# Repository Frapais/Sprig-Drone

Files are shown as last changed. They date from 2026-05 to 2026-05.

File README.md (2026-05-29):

# Sprig-Drone — a single-board Flix drone for the Sprig-C3

A compact, single-board build of the open source [**Flix**](https://github.com/okalachev/flix)
quadcopter, designed around the [**Sprig-C3**](https://github.com/Frapais/Sprig-C3)
(ESP32-C3) microcontroller. The PCB integrates the IMU, motor drivers, LEDs and
battery connector, and doubles as the drone's frame — so the whole aircraft
(minus the microcontroller) is a single board.

This repository contains the **firmware** (a modified version of the Flix
Arduino firmware) and the **hardware** documentation needed to build or buy the
drone.

> **Credit & lineage.** This project is based on the Flix open source quadcopter
> by **Oleg Kalachev** — <https://github.com/okalachev/flix> — used and modified
> under the MIT License. Flix provides the flight control firmware, the
> attitude estimator, the MAVLink/QGroundControl integration and the overall
> architecture. This repo adapts that work to the Sprig-C3 board and adds a few
> hardware-specific features (see [What's different](CHANGES.md)).
> Huge thanks to Oleg and the Flix community.

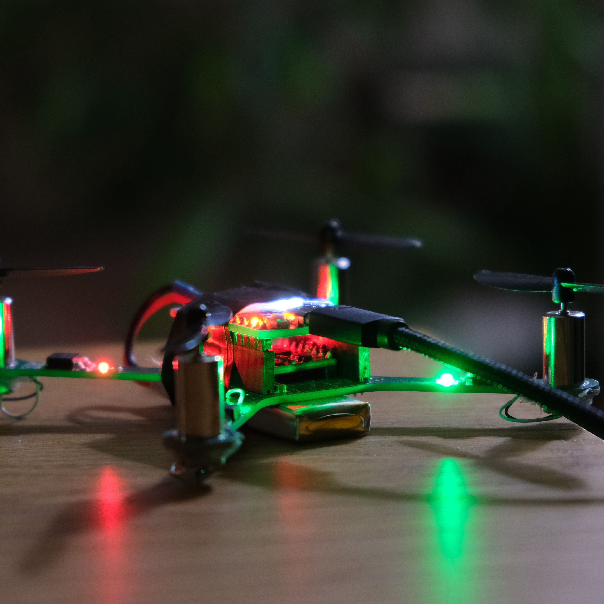
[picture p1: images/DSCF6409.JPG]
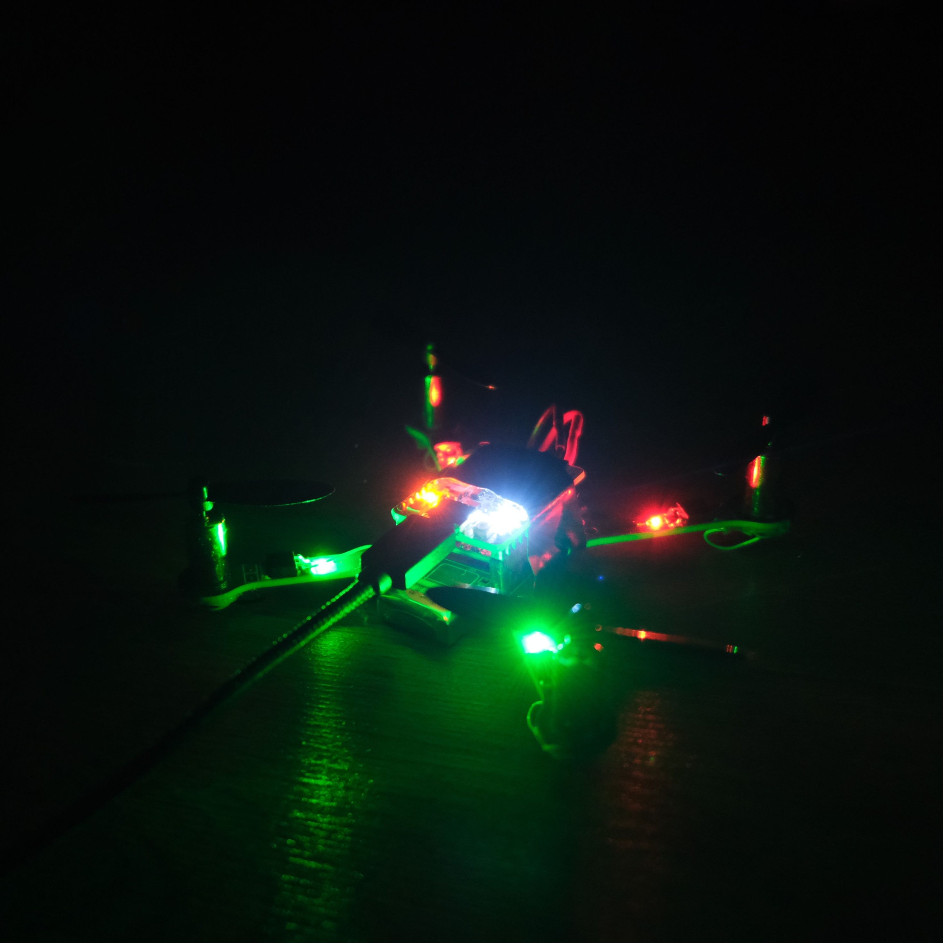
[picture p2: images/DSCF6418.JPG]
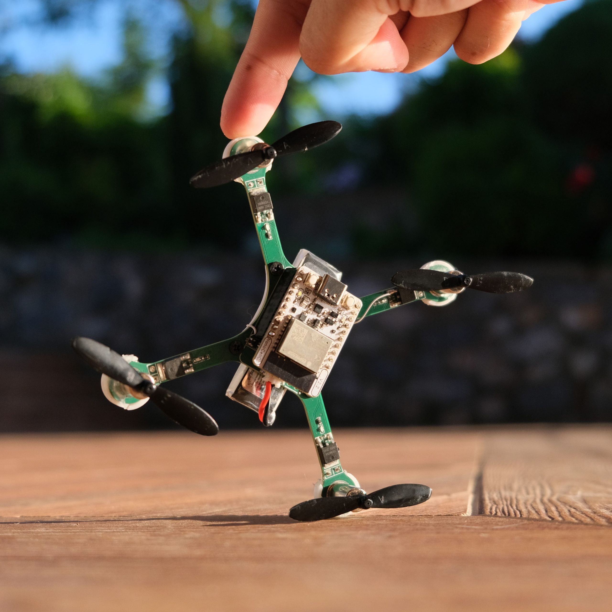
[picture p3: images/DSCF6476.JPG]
|  |  |  |
|---|---|---|

---

## Features

- **Single-board airframe** — IMU, MOSFET motor drivers, status LEDs and battery
  connector integrated into one PCB that is also the chassis.
- **ESP32-C3** flight controller via the Sprig-C3 module.
- **Wi-Fi + MAVLink** control with the QGroundControl app (no RC receiver
  required).
- **I²C IMU** support: ICM-20948 or MPU-6050 (both from the Flix-compatible list).
- **On-board fuel-gauge** battery telemetry via the Sprig-C3's MAX17048.
- **Status LED indicator** driven through a MOSFET (calibration / armed / low
  battery states).
- Brushed **8520** coreless motors, same geometry as the reference Flix.

## What's different from upstream Flix

This firmware tracks upstream Flix and changes only what the Sprig-C3 hardware
requires. The notable modifications:

| Area | Change |
|---|---|
| IMU bus | Switched from SPI (MPU-9250) to **I²C**; supports **ICM-20948** and **MPU-6050** on `Wire` (SDA = GPIO2, SCL = GPIO3). |
| Motor PWM | Frequency lowered to **39 kHz** (ESP32-C3 LEDC max at 10-bit) and pins remapped to the Sprig-C3 layout. |
| Strapping pins | Motor pins chosen to avoid GPIO8/GPIO9 (ESP32-C3 boot strapping pins). |
| Gyro calibration | Faster bias convergence and an **arm gate** that blocks arming until the gyro bias has settled. |
| Power | New **MAX17048 fuel-gauge** driver reporting true voltage and state-of-charge to QGroundControl, with automatic fallback to the analog path. |
| LED | Status-indicator logic on a MOSFET-driven LED bank (GPIO0). |

A full list of changed files and rationale is in [`docs/CHANGES.md`](docs/CHANGES.md).

## Hardware

| Component | Choice |
|---|---|
| Flight controller | Sprig-C3 (ESP32-C3) |
| IMU | ICM-20948 or MPU-6050 (I²C, address `0x68`) |
| Motors | 8520 coreless brushed, 3.7 V |
| Motor drivers | logic-level N-channel MOSFETs (e.g. 100N03A) with gate pull-downs |
| Battery | 1S Li-Ion / LiPo (e.g. 18650 for bench testing) |
| Fuel gauge | MAX17048 (on the Sprig-C3, I²C `0x36`) |

### Pin mapping (Sprig-C3)

| Function | GPIO |
|---|---|
| I²C SDA (IMU + fuel gauge) | 2 |
| I²C SCL (IMU + fuel gauge) | 3 |
| Motor — rear left  | 7 |
| Motor — rear right | 10 |
| Motor — front right | 6 |
| Motor — front left | 5 |
| Status LED (MOSFET gate) | 0 |

> ⚠️ **Do not** put motor or LED MOSFET gates on **GPIO8** or **GPIO9** — they are
> ESP32-C3 boot strapping pins and a gate pull-down on them holds the pin low at
> boot, preventing the chip from initialising (the I²C/IMU bus comes up dead).

Hardware design files and the schematic are in [`hardware/`](hardware/).
**Buy the assembled board:** <https://sprig-labs.com> <!-- update with the exact product link -->

## Firmware setup

> The build process follows upstream Flix closely. See the
> [Flix build guide](https://github.com/okalachev/flix/blob/master/docs/build.md)
> for the general workflow; the Sprig-C3 specifics are below.

1. **Install the Arduino IDE** and the **ESP32 board package** (esp32 by Espressif,
   core 3.x). Select **"ESP32C3 Dev Module"** as the board.
2. **Install libraries** (Library Manager):
   - `FlixPeriph` (latest) — IMU and SBUS drivers.
   - `SparkFun MAX1704x Fuel Gauge` — battery fuel gauge.
   - `MAVLink` — as required by upstream Flix.
3. **Open the sketch:** open the [`flix/`](flix) folder (the sketch is `flix/flix.ino`).
4. **Select the IMU** in `flix/imu.ino` if you are not using the default
   (ICM-20948). For MPU-6050, the declaration is already provided — see comments.
5. **Flash** the board.
6. **First boot:** the firmware creates a Wi-Fi network. On a fresh board, run
   `preset` in the CLI to load the Sprig-C3 default parameters.
7. **Calibrate** the accelerometer (QGroundControl level-horizon calibration, or
   the `ca` CLI command).

### Flying with QGroundControl

1. Power the drone from the battery.
2. Connect your phone/computer to the **`flix`** Wi-Fi network (password
   `flixwifi`).
3. Open **QGroundControl** — it connects automatically and shows telemetry.
4. Enable the **Virtual Joystick** in settings (disable Auto-Center Throttle).
5. Let the drone sit still for ~5 s so the gyro calibrates, then arm and fly.

See [`docs/SETUP.md`](docs/SETUP.md) for detailed setup, tuning and troubleshooting.

## Repository layout

```
Sprig-Drone/
├── flix - Sprig/              # Arduino firmware (sketch folder; open flix/flix.ino)
├── hardware/          # PCB schematic, design files, BOM
├── docs/              # Setup, changes, troubleshooting, images
├── LICENSE            # MIT (upstream Flix + Sprig Labs modifications)
└── README.md
```

## Video

<!-- Add your YouTube build/showcase video link here -->
A full build and flight video is on YouTube: _coming soon_.

## License

This project is released under the **MIT License** — see [`LICENSE`](LICENSE).
The firmware is a derivative of [Flix](https://github.com/okalachev/flix) by Oleg
Kalachev, also MIT-licensed; the original copyright notices are retained in the
source files. You are free to use, modify, and sell — please keep the attribution.

Hardware design files (if/where included) are licensed separately; see
[`hardware/README.md`](hardware/README.md).

## Acknowledgements

- **Oleg Kalachev** and the [Flix project](https://github.com/okalachev/flix) — the
  firmware, flight controller and the whole foundation this builds on.
- The [FlixPeriph](https://github.com/okalachev/flixperiph) peripheral library.
- The open source quadcopter community.

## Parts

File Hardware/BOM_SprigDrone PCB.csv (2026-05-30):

No. | Quantity | Comment | Designator | Footprint | Value | Manufacturer Part | Supplier Part
1 | 1 | HX PH2.0-2PWT | BAT | CONN-SMD_2P-P2.00 |  | HX PH2.0-2PWT | C22461285
2 | 3 | 100nF | C5,C6,C7 | C0603 | 100nF | CC0603KRX7R9BB104 | C14663
3 | 8 | 47uF | C09,C10,C11,C12,C15,C16,C17,C19 | C0805 | 47uF | JMK212BJ476MG-T | C87159
4 | 4 | KF332J-3.5-2P BLACK | H1,H2,H3,H4 | HDR-TH_2P-P3.50-V-M_1 |  | KF332J-3.5-2P BLACK | C19711761
5 | 3 | TMM-101-01-G-S | H5,H6,H7 | HDR-TH_TMM-101-06-L-S |  | TMM-101-01-G-S | C5986197
6 | 2 | XL-1608SURC-06 | LED1,LED2 | LED0603-RD_RED |  | XL-1608SURC-06 | C965799
7 | 2 | PSC-1608U50GC-G4 | LED3,LED4 | LED0603-RD_GREEN |  | PSC-1608U50GC-G4 | C22371298
8 | 5 | 100N03A | Q1,Q2,Q3,Q4,Q6 | TO-252-2_L6.6-W6.1-P4.57-LS9.9-BR-CW |  | 100N03A | C668200
9 | 1 | SI2302-HXY | Q5 | SOT-23-3_L2.9-W1.3-P1.90-LS2.4-BR |  | SI2302-HXY | C4748714
10 | 8 | 10kΩ | R1,R2,R3,R4,R9,R10,R13,R14 | R0603 | 10kΩ | 0603WAF1002T5E | C25804
11 | 4 | 470Ω | R5,R6,R7,R8 | R0603 | 470Ω | 0603WAF4700T5E | C23179
12 | 1 | MK-12C03-G015 | SW3 | SW-SMD_MK-12C03-G015 |  | MK-12C03-G015 | C2890358
13 | 1 | NanoCell | U1 | NanoCell
14 | 1 | MPU-6050 module | U2 | MPU-6050 module
15 | 1 | XC6206P182MR | U5 | SOT-23-3_L2.9-W1.6-P1.90-LS2.8-BR |  | XC6206P182MR | C22466430
16 | 1 | ICM-20948 | U6 | QFN-24_L3.0-W3.0-P0.40-BL-EP |  | ICM-20948 | C726001

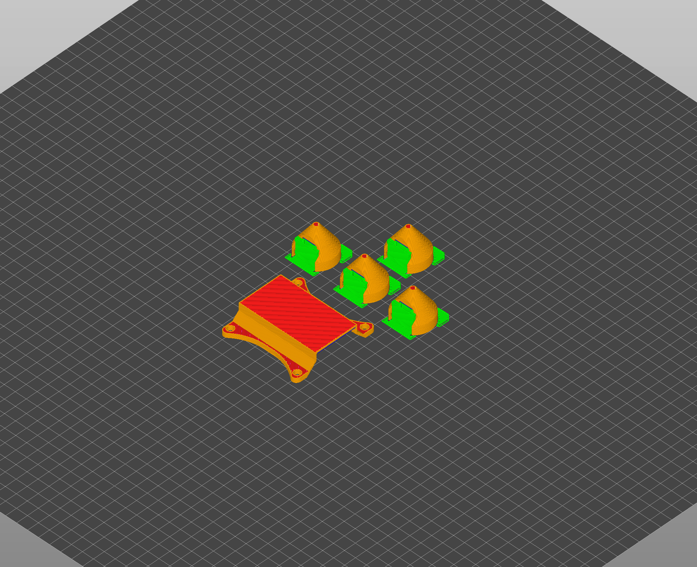
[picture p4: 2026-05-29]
3D files/3d parts sliced.png

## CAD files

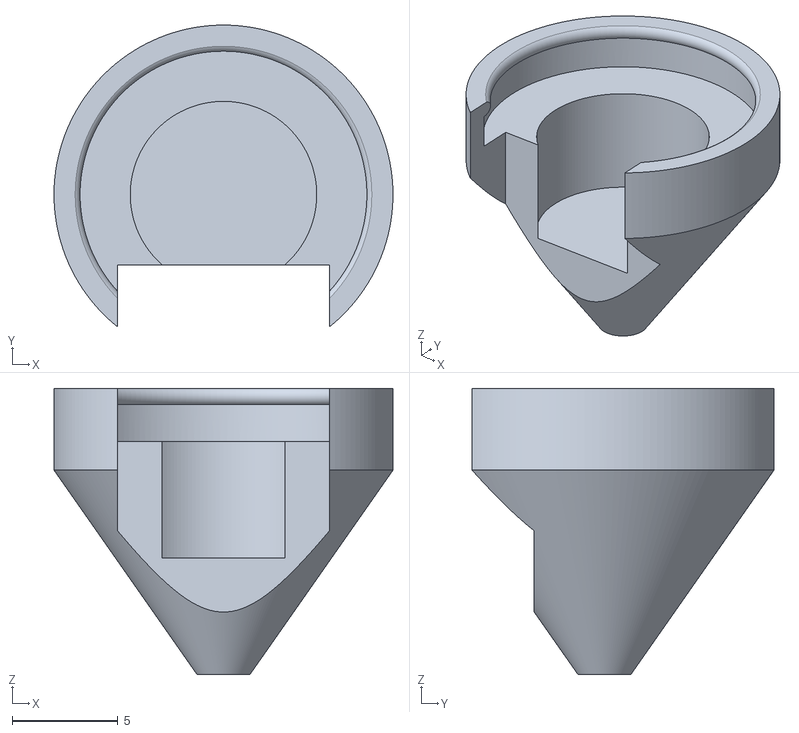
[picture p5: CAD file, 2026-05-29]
3D files/Drone foot.stl
16.0 x 14.2 x 13.5

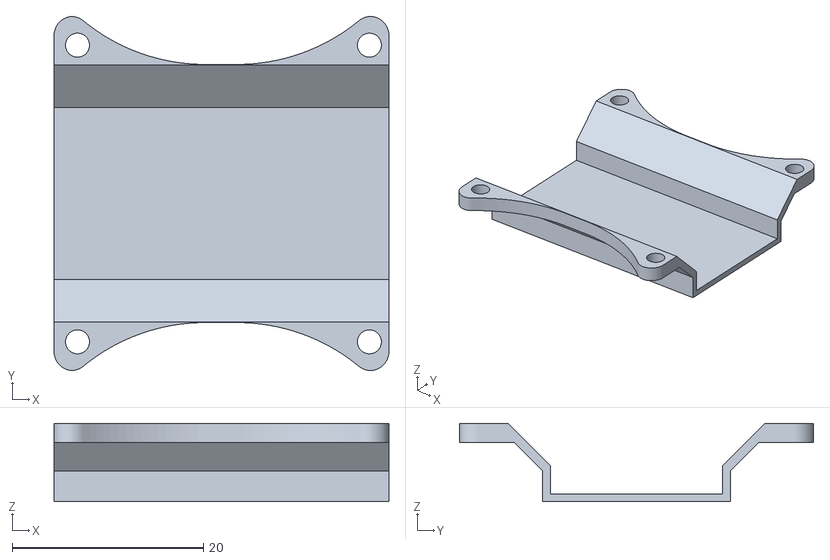
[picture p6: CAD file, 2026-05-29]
3D files/drone battery mount.stl
35.0 x 37.0 x 8.20

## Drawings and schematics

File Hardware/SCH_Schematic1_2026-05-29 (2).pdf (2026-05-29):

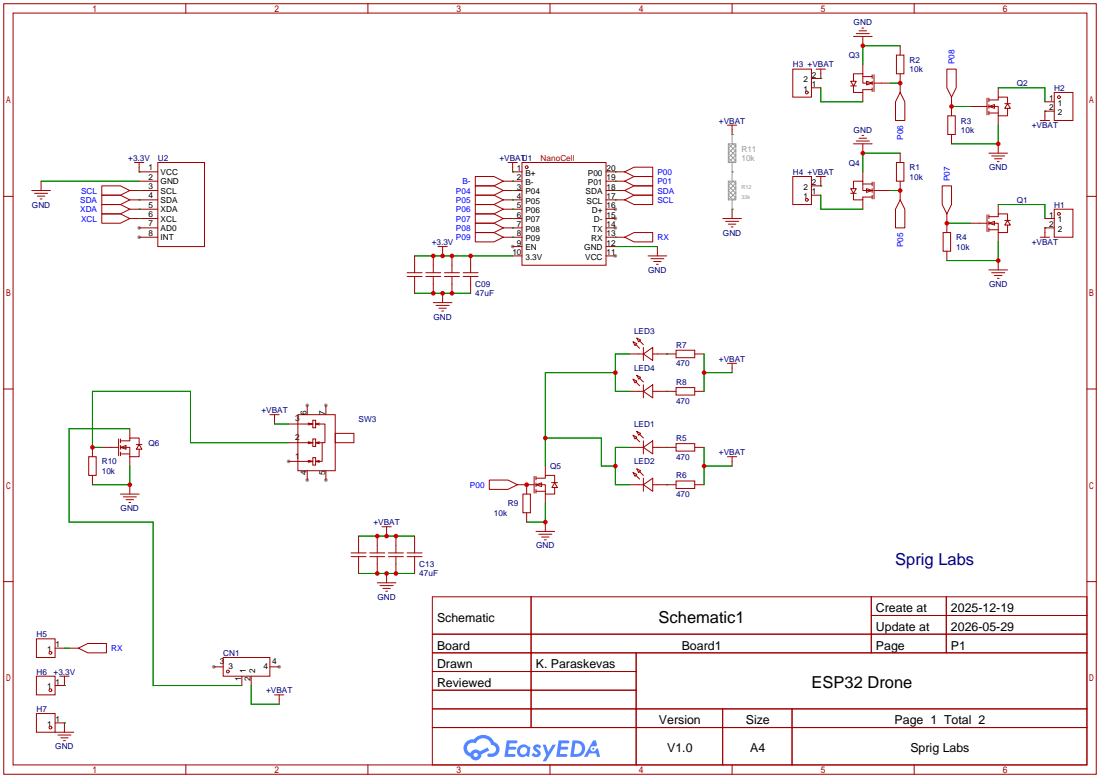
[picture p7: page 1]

Schematic | Schematic1 | Create at | 2025-12-19

Update at | 2026-05-29

Board | Board1 | Page | P1
Drawn | K. Paraskevas | ESP32 Drone
Reviewed

Version | Size | Page 1 Total 2
V1.0 | A4 | Sprig Labs

# VDD 13 NC 14 NC 15 NC 16 NC 17 GND 18 RESV ¹⁹

# GND GNDGND

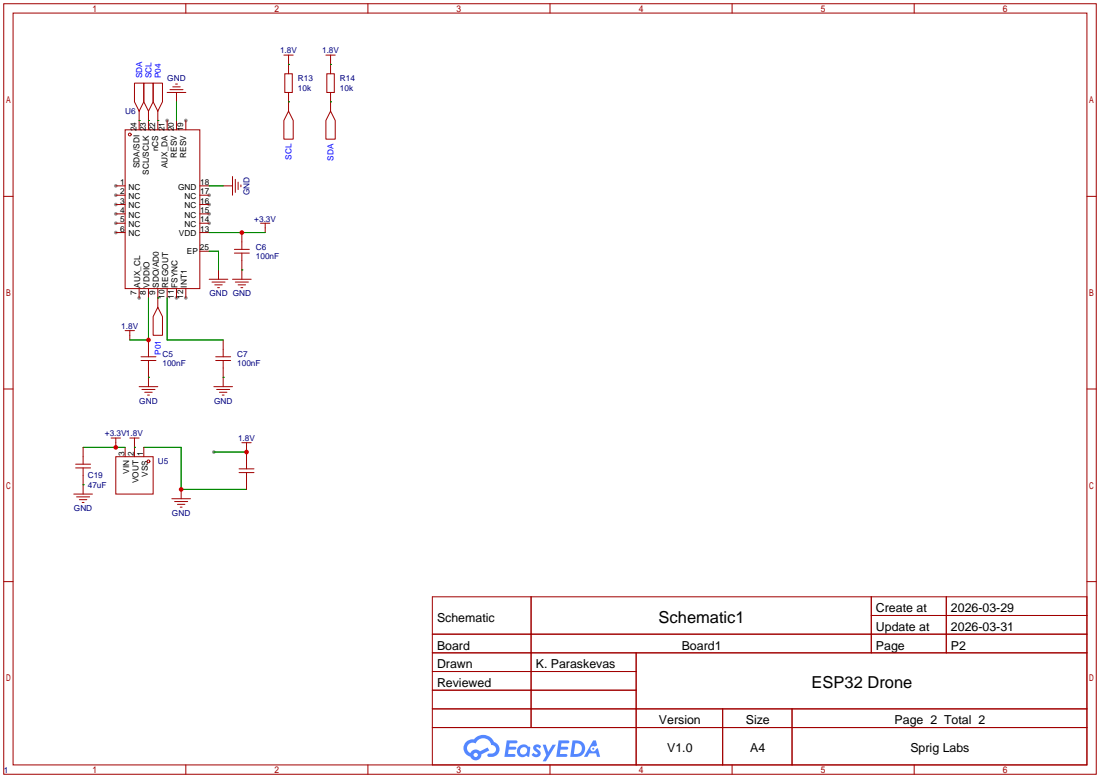
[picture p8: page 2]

Schematic | Schematic1 | Create at | 2026-03-29

Update at | 2026-03-31

Board | Board1 | Page | P2
Drawn | K. Paraskevas | ESP32 Drone
Reviewed

Version | Size | Page 2 Total 2
V1.0 | A4 | Sprig Labs

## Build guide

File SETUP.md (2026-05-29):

# Setup, tuning & troubleshooting

## Prerequisites

- Arduino IDE with the **ESP32 board package** (Espressif, core 3.x).
- Board selection: **ESP32C3 Dev Module**.
- Libraries (Library Manager):
  - **FlixPeriph** (latest) — IMU + SBUS drivers.
  - **SparkFun MAX1704x Fuel Gauge** — battery telemetry.
  - **MAVLink** — required by upstream Flix.
- **QGroundControl** app on a phone or computer.

## Choosing the IMU

The firmware defaults to the **ICM-20948**. To use an **MPU-6050**, change the
IMU declaration at the top of `flix/imu.ino` (see the comments there). Both use
I²C address `0x68` by default — if your breakout uses `0x69`, change
`IMU_I2C_ADDR`. Confirm detection with the `imu` CLI command:
- ICM-20948 → `who am I: 0xEA`
- MPU-6050 → `who am I: 0x68`

## First boot

1. Flash the firmware.
2. Connect to the **`flix`** Wi-Fi network (password `flixwifi`).
3. Open the CLI (wireless, or the Arduino Serial Monitor) and run **`preset`** to
   load the Sprig-C3 default parameters. *Do this once on a fresh board* — the
   firmware persists parameters in flash, and `preset` ensures the source-code
   defaults (pins, PWM frequency, fuel-gauge enable) are applied.
4. Run the accelerometer calibration: `ca` in the CLI, or QGroundControl's
   level-horizon calibration. Re-run this if you swap the IMU.

## Verifying motors

With **props removed**, use the CLI motor-test commands and confirm the correct
motor spins:
- `mfl` → front left, `mfr` → front right, `mrl` → rear left, `mrr` → rear right.

If the wrong motor spins, the pin-to-motor mapping is off. Set it live without
reflashing:

```
par MOT_PIN_FL 5
par MOT_PIN_FR 6
par MOT_PIN_RL 7
par MOT_PIN_RR 10
```

Then reboot. Also confirm spin **direction**: FL and RR turn one way, FR and RL
the other. Reverse a brushed motor by swapping its two leads.

## Flying

1. Power from the battery.
2. Join the `flix` Wi-Fi; open QGroundControl (connects automatically).
3. Enable **Virtual Joystick**; disable **Auto-Center Throttle**.
4. Let the drone sit still ~5 s — the gyro must calibrate before it will arm
   (the status LED is solid off until calibrated, then slow-blinks when ready).
5. Arm and fly.

## Tuning (if it oscillates)

The controller is a two-level cascade PID (outer attitude loop → inner rate
loop). All gains are live parameters — adjust in QGroundControl or via `par`,
no reflash needed. Roll and pitch share gains; change them together.

- **Fast oscillation / buzz, worse on stick input** → inner rate loop too hot.
  Try `CTL_R_RATE_D = 0` / `CTL_P_RATE_D = 0` first (the MPU-6050 is noisy and
  often flies better with no D-term), then lower `CTL_R_RATE_P` / `CTL_P_RATE_P`
  in ~20–25 % steps.
- **Slow wobble that builds** → lower rate I (`CTL_R_RATE_I` / `CTL_P_RATE_I`).
- **Sluggish, won't hold angle** → raise the outer loop P (`CTL_R_P` / `CTL_P_P`).

Change one gain at a time, in calm conditions. Distinguish **oscillation** (PID)
from **vibration** (mechanical): if the attitude readout shakes when you tap the
frame with motors off, soft-mount the IMU and balance the props — no PID value
fixes vibration.

## Troubleshooting

**IMU not detected (`who am I: 0x00`, `ERROR`).**
- Check the I²C address (`0x68` vs `0x69`).
- Make sure nothing is wired to **GPIO8/GPIO9** with a pull-down — a MOSFET gate
  pull-down on a strapping pin holds it low at boot and kills the I²C bus.
- Inspect for solder bridges between SDA/SCL (GPIO2/3) and adjacent pins; reflow
  the I²C and IMU power/ground joints. Measure SDA-to-GND and SCL-to-GND — both
  should idle near 3.3 V thanks to the pull-ups.

**Fuel gauge not reporting.**
- The MAX17048 is powered from the battery cell, not 3.3 V — connect a battery.
- Disable it with `par PWR_FG_ENABLE 0` to fall back to analog if needed.

**LED doesn't light (MOSFET-driven).**
- Confirm the MOSFET gate has a pull-down and the LED bank has current-limiting
  resistors. Measure the GPIO while running: disarm so the LED slow-blinks
  (1 Hz), which a multimeter can track.
- GPIO0 is usable but is also ADC1_CH0; if it misbehaves, move the gate to a
  free pin (e.g. GPIO1) and update `LED_BUILTIN`.

**Gyro drifts right after arming.**
- Let the drone sit still longer before arming; the bias filter must converge.
  The arm gate should prevent this, but a very quick arm on a cold board can
  still catch the tail of convergence.

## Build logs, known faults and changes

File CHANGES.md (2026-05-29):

# Changes from upstream Flix

This firmware is a derivative of [Flix](https://github.com/okalachev/flix) by
Oleg Kalachev. It aims to stay close to upstream and only change what the
Sprig-C3 single-board hardware requires. This document lists the modifications
so the diff against upstream is easy to follow.

## `imu.ino`
- Switched the IMU interface from **SPI (MPU-9250)** to **I²C**.
- Declares the IMU as **ICM-20948** (default) or **MPU-6050** on `Wire`, address
  `0x68`, no data-ready pin (timer-interrupt mode).
- `setupIMU()` initialises the I²C bus on **GPIO2 (SDA) / GPIO3 (SCL)** at 400 kHz
  before starting the sensor.
- Faster gyro-bias low-pass filter and a `gyroCalibrated` convergence flag.

## `motors.ino`
- Motor pins remapped to the Sprig-C3 layout (rear-left 7, rear-right 10,
  front-right 6, front-left 5).
- PWM frequency lowered from 78 kHz to **39 kHz** (ESP32-C3 LEDC limit at 10-bit).
- Motors kept off **GPIO8/GPIO9** (boot strapping pins).

## `control.ino`
- Added an **arm gate**: arming and motor output are blocked until the gyro bias
  has converged (`gyroCalibrated`). Guards every arm path (CLI, MAVLink, RC).

## `power.ino`
- New **MAX17048 fuel-gauge** driver (SparkFun MAX1704x library) reporting true
  battery voltage and state-of-charge over I²C (`0x36`).
- Exposes `batteryRemaining` (0–1) for MAVLink telemetry.
- Automatic fallback to the original analog-voltage path if the fuel gauge is
  not present, selectable via the `PWR_FG_ENABLE` parameter.

## `mavlink.ino`
- `BATTERY_STATUS` uses the fuel-gauge state-of-charge when available, falling
  back to the legacy voltage-to-percentage approximation otherwise.

## `led.ino`
- Status-indicator logic for a **MOSFET-driven LED bank on GPIO0**:
  solid off = gyro calibrating, slow blink = disarmed, fast blink = armed,
  very fast = low battery. `LED_ACTIVE_LOW` selectable for wiring polarity.

## `flix.ino`
- Calls `updateLED()` from the main loop.

## `parameters.ino`
- Added the `PWR_FG_ENABLE` parameter (and its `extern`) for the fuel gauge.

---

All original `// Copyright (c) 2023 Oleg Kalachev` headers are retained; a
`// Modifications (c) 2026 Sprig Labs` line is added to the files changed here.

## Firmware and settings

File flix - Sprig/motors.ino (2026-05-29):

// Copyright (c) 2023 Oleg Kalachev <okalachev@gmail.com>
// Repository: https://github.com/okalachev/flix

// PWM control for motors

#include "util.h"

float motors[4]; // normalized motor thrusts in range [0..1]

// Motor pin mapping for the Sprig-C3 (ESP32-C3) build:
//   index 0 = rear left, 1 = rear right, 2 = front right, 3 = front left
int motorPins[4] = {6, 5, 7, 4};
// ESP32-C3 LEDC max frequency at 10-bit resolution is ~39 kHz, so the motor
// PWM frequency must be lowered from 78000 (used on the original ESP32 build).
int pwmFrequency = 39000;
int pwmResolution = 10;
int pwmStop = 0;
int pwmMin = 0;
int pwmMax = -1; // -1 means duty cycle mode

const int MOTOR_REAR_LEFT = 0;
const int MOTOR_REAR_RIGHT = 1;
const int MOTOR_FRONT_RIGHT = 2;
const int MOTOR_FRONT_LEFT = 3;

void setupMotors() {
	print("Setup Motors\n");
	// configure pins
	for (int i = 0; i < 4; i++) {
		ledcAttach(motorPins[i], pwmFrequency, pwmResolution);
		pwmFrequency = ledcChangeFrequency(motorPins[i], pwmFrequency, pwmResolution); // when reconfiguring
	}
	sendMotors();
	print("Motors initialized\n");
}

void sendMotors() {
	for (int i = 0; i < 4; i++) {
		ledcWrite(motorPins[i], getDutyCycle(motors[i]));
	}
}

int getDutyCycle(float value) {
	value = constrain(value, 0, 1);
	if (pwmMax >= 0) { // pwm mode
		float pwm = mapf(value, 0, 1, pwmMin, pwmMax);
		if (value == 0) pwm = pwmStop;
		float duty = mapf(pwm, 0, 1000000 / pwmFrequency, 0, (1 << pwmResolution) - 1);
		return round(duty);
	} else { // duty cycle mode
		return round(value * ((1 << pwmResolution) - 1));
	}
}

bool motorsActive() {
	return motors[0] != 0 || motors[1] != 0 || motors[2] != 0 || motors[3] != 0;
}

void testMotor(int n) {
	print("Testing motor %d\n", n);
	motors[n] = 0.2;
	delay(50); // ESP32 may need to wait until the end of the current cycle to change duty https://github.com/espressif/arduino-esp32/issues/5306
	sendMotors();
	pause(3);
	motors[n] = 0;
	sendMotors();
	print("Done\n");
}

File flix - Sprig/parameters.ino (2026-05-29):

// Copyright (c) 2024 Oleg Kalachev <okalachev@gmail.com>
// Repository: https://github.com/okalachev/flix

// Parameters storage in flash memory

#include <Preferences.h>
#include "util.h"

extern int channelZero[16];
extern int channelMax[16];
extern int rollChannel, pitchChannel, throttleChannel, yawChannel, armedChannel, modeChannel;
extern int rcRxPin;
extern int wifiMode, udpLocalPort, udpRemotePort;
extern float rcLossTimeout, descendTime;
extern int voltagePin;
extern float voltageScale;
extern LowPassFilter<float> voltageFilter;
extern int fuelGaugeEnabled;

Preferences storage;

struct Parameter {
	const char *name; // max length is 15
	bool integer;
	union { float *f; int *i; }; // pointer to the variable
	float cache; // what's stored in flash
	void (*callback)(); // called after parameter change
	Parameter(const char *name, float *variable, void (*callback)() = nullptr) : name(name), integer(false), f(variable), callback(callback) {};
	Parameter(const char *name, int *variable, void (*callback)() = nullptr) : name(name), integer(true), i(variable), callback(callback) {};
	float getValue() const { return integer ? *i : *f; };
	void setValue(const float value) { if (integer) *i = value; else *f = value; };
};

Parameter parameters[] = {
	// control
	{"CTL_R_RATE_P", &rollRatePID.p},
	{"CTL_R_RATE_I", &rollRatePID.i},
	{"CTL_R_RATE_D", &rollRatePID.d},
	{"CTL_R_RATE_WU", &rollRatePID.windup},
	{"CTL_R_RATE_D_A", &rollRatePID.lpf.alpha},
	{"CTL_P_RATE_P", &pitchRatePID.p},
	{"CTL_P_RATE_I", &pitchRatePID.i},
	{"CTL_P_RATE_D", &pitchRatePID.d},
	{"CTL_P_RATE_WU", &pitchRatePID.windup},
	{"CTL_P_RATE_D_A", &pitchRatePID.lpf.alpha},
	{"CTL_Y_RATE_P", &yawRatePID.p},
	{"CTL_Y_RATE_I", &yawRatePID.i},
	{"CTL_Y_RATE_D", &yawRatePID.d},
	{"CTL_Y_RATE_D_A", &yawRatePID.lpf.alpha},
	{"CTL_R_P", &rollPID.p},
	{"CTL_R_I", &rollPID.i},
	{"CTL_R_D", &rollPID.d},
	{"CTL_P_P", &pitchPID.p},
	{"CTL_P_I", &pitchPID.i},
	{"CTL_P_D", &pitchPID.d},
	{"CTL_Y_P", &yawPID.p},
	{"CTL_P_RATE_MAX", &maxRate.y},
	{"CTL_R_RATE_MAX", &maxRate.x},
	{"CTL_Y_RATE_MAX", &maxRate.z},
	{"CTL_TILT_MAX", &tiltMax},
	{"CTL_FLT_MODE_0", &flightModes[0]},
	{"CTL_FLT_MODE_1", &flightModes[1]},
	{"CTL_FLT_MODE_2", &flightModes[2]},
	// imu
	{"IMU_ROT_ROLL", &imuRotation.x},
	{"IMU_ROT_PITCH", &imuRotation.y},
	{"IMU_ROT_YAW", &imuRotation.z},
	{"IMU_ACC_BIAS_X", &accBias.x},
	{"IMU_ACC_BIAS_Y", &accBias.y},
	{"IMU_ACC_BIAS_Z", &accBias.z},
	{"IMU_ACC_SCALE_X", &accScale.x},
	{"IMU_ACC_SCALE_Y", &accScale.y},
	{"IMU_ACC_SCALE_Z", &accScale.z},
	{"IMU_GYRO_BIAS_A", &gyroBiasFilter.alpha},
	// estimate
	{"EST_ACC_WEIGHT", &accWeight},
	{"EST_LVL_WEIGHT", &levelWeight},
	{"EST_RATES_LPF_A", &ratesFilter.alpha},
	// motors
	{"MOT_PIN_FL", &motorPins[MOTOR_FRONT_LEFT], setupMotors},
	{"MOT_PIN_FR", &motorPins[MOTOR_FRONT_RIGHT], setupMotors},
	{"MOT_PIN_RL", &motorPins[MOTOR_REAR_LEFT], setupMotors},
	{"MOT_PIN_RR", &motorPins[MOTOR_REAR_RIGHT], setupMotors},
	{"MOT_PWM_FREQ", &pwmFrequency, setupMotors},
	{"MOT_PWM_RES", &pwmResolution, setupMotors},
	{"MOT_PWM_STOP", &pwmStop},
	{"MOT_PWM_MIN", &pwmMin},
	{"MOT_PWM_MAX", &pwmMax},
	// rc
	{"RC_RX_PIN", &rcRxPin, setupRC},
	{"RC_ZERO_0", &channelZero[0]},
	{"RC_ZERO_1", &channelZero[1]},
	{"RC_ZERO_2", &channelZero[2]},
	{"RC_ZERO_3", &channelZero[3]},
	{"RC_ZERO_4", &channelZero[4]},
	{"RC_ZERO_5", &channelZero[5]},
	{"RC_ZERO_6", &channelZero[6]},
	{"RC_ZERO_7", &channelZero[7]},
	{"RC_MAX_0", &channelMax[0]},
	{"RC_MAX_1", &channelMax[1]},
	{"RC_MAX_2", &channelMax[2]},
	{"RC_MAX_3", &channelMax[3]},
	{"RC_MAX_4", &channelMax[4]},
	{"RC_MAX_5", &channelMax[5]},
	{"RC_MAX_6", &channelMax[6]},
	{"RC_MAX_7", &channelMax[7]},
	{"RC_ROLL", &rollChannel},
	{"RC_PITCH", &pitchChannel},
	{"RC_THROTTLE", &throttleChannel},
	{"RC_YAW", &yawChannel},
	{"RC_MODE", &modeChannel},
	// wifi
	{"WIFI_MODE", &wifiMode},
	{"WIFI_PORT_LOC", &udpLocalPort},
	{"WIFI_PORT_REM", &udpRemotePort},
	// mavlink
	{"MAV_SYS_ID", &mavlinkSysId},
	{"MAV_RATE_SLOW", &telemetrySlow.rate},
	{"MAV_RATE_FAST", &telemetryFast.rate},
	// power
	{"PWR_FG_ENABLE", &fuelGaugeEnabled, setupPower},
	{"PWR_VOLT_PIN", &voltagePin},
	{"PWR_VOLT_SCALE", &voltageScale},
	{"PWR_VOLT_LPF_A", &voltageFilter.alpha},
	// safety
	{"SF_RC_LOSS_TIME", &rcLossTimeout},
	{"SF_DESCEND_TIME", &descendTime},
};

void setupParameters() {
	print("Setup parameters\n");
	storage.begin("flix");
	// Read parameters from storage
	for (auto &parameter : parameters) {
		if (!storage.isKey(parameter.name)) {
			storage.putFloat(parameter.name, parameter.getValue()); // store default value
		}
		parameter.setValue(storage.getFloat(parameter.name, 0));
		parameter.cache = parameter.getValue();
	}
}

int parametersCount() {
	return sizeof(parameters) / sizeof(parameters[0]);
}

const char *getParameterName(int index) {
	if (index < 0 || index >= parametersCount()) return "";
	return parameters[index].name;
}

float getParameter(int index) {
	if (index < 0 || index >= parametersCount()) return NAN;
	return parameters[index].getValue();
}

float getParameter(const char *name) {
	for (auto &parameter : parameters) {
		if (strcasecmp(parameter.name, name) == 0) {
			return parameter.getValue();
		}
	}
	return NAN;
}

bool setParameter(const char *name, const float value) {
	for (auto &parameter : parameters) {
		if (strcasecmp(parameter.name, name) == 0) {
			if (parameter.integer && !isfinite(value)) return false; // can't set integer to NaN or Inf
			parameter.setValue(value);
			if (parameter.callback) parameter.callback();
			return true;
		}
	}
	return false;
}

void syncParameters() {
	static Rate rate(1);
	if (!rate) return; // sync once per second
	if (motorsActive()) return; // don't use flash while flying, it may cause a delay

	for (auto &parameter : parameters) {
		if (parameter.getValue() == parameter.cache) continue; // no change
		if (isnan(parameter.getValue()) && isnan(parameter.cache)) continue; // both are NAN

		storage.putFloat(parameter.name, parameter.getValue());
		parameter.cache = parameter.getValue(); // update cache
	}
}

void printParameters() {
	for (auto &parameter : parameters) {
		print("%s = %g\n", parameter.name, parameter.getValue());
	}
}

void resetParameters() {
	storage.clear();
	ESP.restart();
}

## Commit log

2026-05-29 Added assembled photos
2026-05-29 Added 3D files
    [Drone foot.stl, drone battery mount.stl]
2026-05-30 Added BOM
    [BOM_SprigDrone PCB.csv]
